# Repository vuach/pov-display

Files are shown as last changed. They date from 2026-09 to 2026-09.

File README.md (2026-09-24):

# ESP32 POV Display

Двухлопастной POV-дисплей на ESP32 с синхронизацией по датчику Холла.

## Текущая конфигурация

- две симметричные лопасти с активной длиной до 150 мм;
- по 20 APA102 на лопасть в первой сборке; до 21 после измерения;
- ESP32 DevKit V1 на роторе;
- шестиканальное токосъёмное кольцо;
- A2212 1000KV для первого прототипа, 1400KV не использовать;
- аккумулятор и ESC остаются на неподвижном основании;
- в односторонней Rev B модуль MP1584 расположен на роторе, через кольцо передаётся VBAT;
- целевой диапазон после механической валидации: 600–2400 RPM.

Проект пока находится на стадии стендовой проверки электроники. Вращение с установленным ротором запрещено до завершения расчёта, балансировки и изготовления закрытого защитного кожуха.

## Структура

- `docs/` — актуальная спецификация, архитектура, план сборки и безопасность;
- `hardware/` — BOM, расчёт питания, кольцо, разъёмы и двухлистовая принципиальная схема EasyEDA;
- `hardware/pcb/board-architecture.md` — окончательное функциональное разделение двух пользовательских плат и количество отверстий;
- `mechanical/` — требования к ротору, схема крепления мотора/ротора и предварительная параметрическая CAD-модель;
- `firmware/` — итоговая проектная прошивка, безопасная конфигурация по умолчанию и отдельно компилируемая полнофункциональная конфигурация;
- `tests/` — протоколы и результаты испытаний;
- `references/` — исходный практикум и фотографии компонентов.

## Ближайший этап

Автономные стендовые проверки полученных компонентов завершены без выявленных проблем. После получения кольца выполнить его прозвонку и нагрузочный тест. Сборка и вращение ротора остаются запрещены до завершения механического крепления, балансировки и защитного кожуха.

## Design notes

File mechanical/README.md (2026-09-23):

# Механическая часть

## Зафиксированная идея

- две геометрически одинаковые лопасти;
- активная длина каждой до 150 мм;
- светодиоды начинаются у ступицы и идут к периферии;
- ESP32, буфер, MP1584 и проводка располагаются максимально близко к оси;
- аккумулятор и ESC остаются на неподвижном основании;
- через кольцо в Rev B передаётся VBAT, а 5 В формируются модулем MP1584 на роторе.

Принцип крепления мотора, неподвижной X-крестовины, вращающегося адаптера и платы описан в [`motor-rotor-mounting.md`](motor-rotor-mounting.md).

## Предварительный материал

Для самих плат-лопастей предпочтителен FR4/G10. Он не должен быть единственным несущим элементом без расчёта и испытаний. Основную центробежную нагрузку должна принимать симметричная металлическая или карбоновая балка и металлическая зажимная ступица. FDM-печать допустима для держателей и кожухов, но не считается доказанно безопасной несущей ступицей.

## Данные, необходимые для CAD

| Параметр | Значение |
|---|---|
| Диаметр/геометрия вала A2212 | TBD |
| Межосевые размеры крепления мотора | TBD |
| Размеры кольца и полого вала | TBD |
| Корневая и активная длина лопасти | TBD / до 150 мм |
| Ширина и толщина FR4/G10 | TBD |
| Масса одной LED-ленты | TBD |
| Масса ESP32, буфера и проводов | TBD |
| Общая масса ротора | TBD |
| Материал несущей балки | TBD |
| Максимальные подтверждённые RPM | 0; вращение не проводилось |
| Принтер и рабочая область | TBD |

Финальную CAD-модель нельзя выпускать, пока эти значения не измерены. Для предварительной проверки компоновки подготовлена параметрическая модель [`cad/preliminary-assembly.scad`](cad/preliminary-assembly.scad). Все неподтверждённые размеры в ней явно отмечены как заглушки.

## Обязательные CAD-узлы

- ступица и соединение с мотором;
- симметричная несущая балка;
- крепления двух лопастей;
- крепление кольца;
- держатель ESP32 и буфера около оси;
- фиксация проводов и разгрузка пайки;
- основание мотора;
- полностью закрытый прозрачный кожух.

X-образная деталь из комплекта A2212 относится к неподвижному креплению корпуса мотора. Она не является ступицей ротора. Лопасти и плата крепятся к отдельной несущей детали, соединённой с вращающимся адаптером двигателя.

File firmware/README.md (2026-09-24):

# ESP32 POV — итоговая проектная прошивка

Версия: `1.0.0-project`.

Прошивка содержит полный предусмотренный программный контур устройства: две APA102-лопасти, синхронизацию Hall, BLE/Serial, хранение изображения и безопасный автомат управления ESC.

Слово «итоговая» относится к составу функций и компиляции. Прошивка не прошла испытания на собранном вращающемся устройстве и сама по себе не разрешает запуск ротора.

## Конфигурации сборки

| Environment | POV | Активный ESC | Назначение |
|---|---:|---:|---|
| `esp32dev` | заблокирован | заблокирован | безопасная сборка по умолчанию |
| `esp32dev-final` | включён | доступен после ARM | полнофункциональная проектная сборка, не прошивать до допуска |

```powershell
cd "C:\Users\vuach\Main Branch\Current\POV Display\firmware"
$env:PLATFORMIO_CORE_DIR="$PWD\.platformio-core"
& .\.venv\Scripts\platformio.exe run
& .\.venv\Scripts\platformio.exe run -e esp32dev-final
```

Команда `run` только компилирует. Она ничего не загружает в ESP32.

## Реализовано

- Hall на GPIO27 с отбрасыванием слишком близких импульсов и фильтрацией периода;
- 120 угловых столбцов, 20 LED на лопасть и сдвиг второй лопасти на 180°;
- два аппаратных SPI: GPIO18/19 и GPIO23/22;
- автоматическое гашение APA102 при потере синхронизации;
- изменение яркости и фазового нуля;
- запись отдельных пикселей, заливка кадра и тестовый рисунок;
- сохранение изображения, яркости и фазы во flash с контрольной суммой;
- двухступенчатое ARM-подтверждение ESC;
- плавное изменение PWM, heartbeat и аварии при потере Hall или превышении RPM;
- безопасные 1000 мкс после загрузки, STOP, потери BLE и любой ошибки ESC.

## Команды Serial и BLE

Serial: `115200`, окончание строки LF или CRLF. BLE-устройство называется `POV-Display`; UUID остались совместимыми с ранней версией.

| Команда | Назначение |
|---|---|
| `PING` | проверка связи |
| `VERSION` | версия прошивки |
| `STATUS` | состояние Hall и ESC |
| `HALL`, `ZERO`, `SIMRPM n` | диагностика датчика и расчёта RPM |
| `POVSTATUS`, `ESCSTATUS` | состояние подсистем |
| `ARM`, затем `ARM CONFIRM` за 3 с | двухступенчатое разрешение ESC |
| `THROTTLE n` | целевой PWM 1000…1600 мкс |
| `KEEPALIVE` | продление разрешения ESC; требуется чаще одного раза в секунду |
| `STOP`, `SAFE`, `OFF`, `DISARM` | 1000 мкс и гашение лопастей |
| `RESETFAULT` | перевод аварии обратно в DISARMED |
| `BRIGHT n` | глобальная яркость APA102, 0…31 |
| `PHASE n` | сдвиг фазового нуля в столбцах |
| `IMAGE CLEAR r g b` | заливка кадра цветом |
| `IMAGE PIXEL column radius r g b` | изменение одного пикселя |
| `IMAGE PATTERN` | восстановление диагностического рисунка |
| `IMAGE SAVE`, `IMAGE LOAD` | запись и чтение кадра из flash |
| `IMAGE STATUS` | параметры буфера изображения |

Передача полного кадра выполняется последовательностью `IMAGE PIXEL`, после чего используется `IMAGE SAVE`. Для удобной эксплуатации позже потребуется отдельное приложение-конвертер, но протокол хранения и изменения произвольного кадра уже реализован.

## Автомат ESC

Состояния: `LOCKED → DISARMED → ARM_PENDING → ARMED → RUNNING`. Любое нарушение переводит управление в `FAULT` и немедленно устанавливает 1000 мкс.

Аварийные условия:

- heartbeat отсутствует более 1 с;
- после начала разгона Hall не появился за 3 с;
- при работающем моторе Hall отсутствует более 0,5 с;
- RPM превышает 2600;
- BLE-соединение разорвано.

PWM изменяется ступенями по 5 мкс каждые 20 мс. Эти значения являются консервативной отправной точкой и должны уточняться по реальному ESC и механике.

## Результат сборки 2026-09-24

Обе конфигурации скомпилированы PlatformIO без ошибок.

| Конфигурация | RAM | Flash |
|---|---:|---:|
| безопасная `esp32dev` | 47 292 байт, 14,4% | 1 154 685 байт, 88,1% |
| функциональная `esp32dev-final` | 47 340 байт, 14,4% | 1 156 669 байт, 88,2% |

Загрузка в ESP32 и физическое испытание этой версии не выполнялись.

## Условия перед использованием функциональной сборки

1. Проверить CH5 кольца осциллографом.
2. Проверить лопасти неподвижно и подтвердить правильный порядок цветов.
3. Проверить аварийные переходы ESC без установленного ротора.
4. Выполнить балансировку и установить закрытый кожух.
5. Только после этого отдельно изменить процедуру допуска к прошивке `esp32dev-final`.

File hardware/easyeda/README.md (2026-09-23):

# EasyEDA

`pov-display-schematic-rev-a.json` — историческая двухлистовая схема стендовой Rev A, в которой MP1584 расположен до кольца. Для односторонней платы ротора Rev B актуальна архитектура с MP1584 на роторе из `docs/architecture-and-wiring.md` и `hardware/pcb/rotor-controller-rev-b-home-etch.md`; Rev A нельзя использовать как монтажную схему Rev B.

`pov-display-electrical-draft.json` — старый структурный черновик. Он сохранён только как обзор архитектуры и не должен использоваться вместо принципиальной схемы.

`exports/pov-display-schematic-rev-a.pdf` — читаемый экспорт Rev A. Исходный JSON обновлён до правила «20 LED по умолчанию, 21 после измерения» позднее PDF-экспорта; после проверки полученной ленты PDF требуется повторно экспортировать из EasyEDA. Электрическая распиновка от этого уточнения не меняется.

Схема предназначена для проверки архитектуры и соединений. Она не является производственной: библиотечные посадочные места, номиналы предохранителей, параметры кольца, полярность разъёмов и маркировку реальных модулей требуется проверить до изготовления.

Ограничение графических примитивов относится только к `pov-display-electrical-draft.json`. В Rev A электрические выводы и цепи присутствуют, однако ERC ещё не считается пройденным: условные символы требуется заменить проверенными библиотечными компонентами, назначить корпуса и сверить номера выводов с полученными деталями.

Основная схема генерируется командой:

```powershell
& "C:\Users\vuach\.cache\codex-runtimes\codex-primary-runtime\dependencies\node\bin\node.exe" "hardware/easyeda/generate-schematic.js"
```

Генератор структурного черновика: `generate-draft.js`.

После генерации файл импортируется через `Файл → Открыть → EasyEDA`.

Карта замены графических блоков компонентами библиотеки и собственными символами приведена в `library-replacement-map.md`.

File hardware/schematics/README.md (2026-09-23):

# Схемы соединений

- `wiring-netlist.csv` — актуальная таблица соединений для Rev B: через токосъёмное кольцо передаётся `VBAT`, а MP1584 установлен на роторе.
- `system-schematic.svg` и `system-schematic.png` — ранняя обзорная схема Rev A. Она оставлена для истории и не должна использоваться как монтажная схема Rev B.

Актуальные пояснения по монтажу находятся в `../assembly-and-wiring.md`, распиновка кольца — в `../slip-ring-pinout.md`, а односторонняя плата — в `../pcb/rotor-controller-rev-b-home-etch.md`.

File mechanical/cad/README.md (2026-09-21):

# Предварительная CAD-модель

Файл `preliminary-assembly.scad` содержит параметрическую компоновку двухлопастного POV-дисплея. Модель предназначена для проверки расположения узлов и оценки требуемого габарита кожуха.

Модель не является производственной. Экспорт деталей для печати, резки или установки на мотор запрещён до замены размеров-заглушек фактическими измерениями и проверки прочности.

## Отражено в модели

- две симметричные лопасти с активной длиной 150 мм;
- по 20 условных светодиодов на лопасть; 21 допускается после измерения;
- центральная несущая балка;
- условные объёмы ступицы, мотора, кольца и электроники;
- запас между концом лопасти и внешним габаритом кожуха;
- раздельное отображение ротора и защитного объёма.

## Размеры-заглушки

| Параметр | Значение в модели | Статус |
|---|---:|---|
| Диаметр вала | 3,2 мм | Только визуальная заглушка |
| Наружный диаметр ступицы | 36 мм | Только визуальная заглушка |
| Диаметр мотора | 28 мм | Только визуальная заглушка |
| Диаметр кольца | 22 мм | Только визуальная заглушка |
| Корневой отступ лопасти | 28 мм | Только компоновочное допущение |
| Ширина лопасти | 22 мм | Только компоновочное допущение |
| Толщина лопасти | 1,5 мм | Только компоновочное допущение |
| Габарит электроники | 58×32×13 мм | Условный объём |

## Использование

1. Установить OpenSCAD.
2. Открыть `preliminary-assembly.scad`.
3. Выбрать `view_mode`: `assembly`, `rotor` или `guard`.
4. После получения компонентов заменить только измеренные параметры.
5. Перед экспортом выполнить отдельный расчёт крепления и прочности.

OpenSCAD в текущем окружении не установлен, поэтому синтаксис подготовлен, но геометрический экспорт и проверка рендера ещё не выполнены.

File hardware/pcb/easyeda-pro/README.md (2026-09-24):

# EasyEDA Pro editable PCB

`rotor-controller-rev-a.kicad_pcb` is the editable interchange source for EasyEDA Pro. It contains the Rev A board outline, through-hole pads, named nets, routed top/bottom copper, mounting holes, top silkscreen envelopes and a bottom GND zone.

Import in EasyEDA Pro using `File -> Import -> KiCad`. EasyEDA Pro expects a ZIP archive, so select `rotor-controller-rev-a-kicad.zip`. The import was verified in EasyEDA Pro V3.2.149 on 2026-09-23: the PCB opened with editable pads, named nets, top/bottom tracks, outline, holes and silkscreen objects.

The standalone `.kicad_pcb` file is kept next to the ZIP as the editable interchange source.

This is a bench prototype. The board is `88 x 64 mm`; it is not mechanically approved for rotation.

## Rev B single-sided rotor carrier

`rotor-controller-rev-b-home-etch-kicad.zip` imports the editable single-sided home-etch revision. All routed copper and the GND zone are on `B.Cu`. Dashed `W1...W10`/`W4A` lines on `F.SilkS` are insulated component-side wire links, not copper tracks. Board size is `110 x 70 mm`.

This revision is an electrical prototype of the rotating-board circuit. It is not the final rotor layout: the revised component and hole requirements are listed in `../board-architecture.md`, while placement waits for the slip-ring and hub dimensions. It also requires a separate structural hub/beam and dynamic balancing before any powered rotation.

Regenerate from the same geometry as the Gerbers:

```powershell
& "C:\Users\vuach\.cache\codex-runtimes\codex-primary-runtime\dependencies\node\bin\node.exe" "hardware/pcb/generate-kicad-pcb.js"
```

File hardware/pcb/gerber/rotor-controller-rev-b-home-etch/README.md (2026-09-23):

# Rotor controller Rev B — home etch

Односторонняя нижняя медь для ручного травления. Компоненты устанавливаются сверху, пайка выполняется снизу. Красные пунктирные соединения на preview выполняются отдельными изолированными проводами сверху.

Печатать `rotor-controller-rev-b-home-etch-bottom-mirrored-1to1.svg` в масштабе 100 %. После печати проверить размер рамки `110 × 70 мм` и примерить ESP32 до травления.

Состав производственного архива:

- `*.GBL` — нижняя медь;
- `*.GKO` — контур платы;
- `*-NPTH.drl` — все отверстия без металлизации;
- `manufacturing.json` — параметры и координаты перемычек;
- `pad-map.csv` — карта площадок;
- `*-preview.svg` и `*-preview.bmp` — монтажный preview;
- `*-bottom-mirrored-1to1.svg` — шаблон тонерного переноса.

Электрическая проверка генератора не заменяет бумажную примерку компонентов, проверку механического крепления и балансировку ротора.

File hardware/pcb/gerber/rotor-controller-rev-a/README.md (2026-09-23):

# Gerber — rotor-controller Rev A

Назначение: первая двухслойная плата контроллера для стендовой электрической сборки ESP32 + SN74AHCT125 + двух ветвей APA102.

## Файлы производства

| Файл | Слой |
|---|---|
| `rotor-controller-rev-a.GTL` | верхняя медь |
| `rotor-controller-rev-a.GBL` | нижняя медь и земляной полигон |
| `rotor-controller-rev-a.GTS` | верхняя маска |
| `rotor-controller-rev-a.GBS` | нижняя маска |
| `rotor-controller-rev-a.GTO` | верхняя шелкография |
| `rotor-controller-rev-a.GKO` | контур платы |
| `rotor-controller-rev-a-PTH.drl` | металлизированные отверстия выводов и переходов |
| `rotor-controller-rev-a-NPTH.drl` | неметаллизированные монтажные отверстия 3,2 мм |
| `pad-map.csv` | координаты, номера выводов и цепи |
| `manufacturing.json` | параметры заказа |
| `rotor-controller-rev-a-preview.svg` | контрольный вид обоих слоёв |
| `rotor-controller-rev-a-preview.bmp` | растровый контрольный вид |

## Параметры

- FR-4, 2 слоя, 1,6 мм;
- медь 1 oz минимум;
- размер 88 × 64 мм;
- минимальная сигнальная дорожка 0,35 мм;
- питание 5 В разведено дорожками 1,2 мм;
- земля — полигон нижнего слоя;
- ESP32 — проверенный footprint Rev B, шаг вдоль ряда 2,52 мм;
- U4 — SN74AHCT125N PDIP-14, не 74HC125;
- J_A/J_B — 1×4, шаг 2,54 мм: `5V`, `GND`, `DI`, `CI`;
- J_RING — 1×6, шаг 2,54 мм: `5V`, `5V`, `GND`, `GND`, `ESC_PWM`, `NC`;
- J_HALL — 1×3: `GND`, `3V3`, `S`.

До нагрузочной проверки суммарный ток двух разъёмов лопастей ограничивается 0,9 А. Геометрия дорожек Rev A не является разрешением использовать максимальный паспортный ток всех APA102.

## Ограничение Rev A

Это электрически трассированный прототип, а не допущенный к вращению ротор. Размеры ступицы, её крепёж, масса сборки и динамическая балансировка ещё не подтверждены. Плату запрещено вращать до переноса проверенной электрической части в механически рассчитанную Rev B Rotor и испытаний в защитном кожухе.

Перед заказом комплект нужно дополнительно открыть в Gerber Viewer производителя и проверить, что контур распознан как `88 × 64 мм`, а сверловка содержит отверстия 1,0/1,1 и 3,2 мм.

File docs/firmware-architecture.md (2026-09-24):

# Архитектура прошивки

## Режимы безопасности

| Флаг сборки | Значение по умолчанию | Что разрешает |
|---|---:|---|
| `POV_DISPLAY_ENABLED` | `0` | Вывод на две APA102 только после изменения на `1` |
| `ENABLE_ESC_ACTIVE_TEST` | `0` | PWM выше безопасных 1000 мкс только после изменения на `1` |

Флаги независимы. Для неподвижного теста светодиодов можно разрешить только POV, оставив ESC заблокированным. Однако текущий рендер начинает вывод только после двух корректных импульсов Hall, необходимых для измерения периода.

## Поток данных

1. Прерывание GPIO27 фиксирует время Hall и отбрасывает импульсы ближе 5 мс.
2. Основной цикл атомарно получает время начала и период оборота.
3. Период принимается только в диапазоне 600–2400 RPM.
4. Время после импульса преобразуется в номер одного из 120 угловых столбцов.
5. Для лопасти A берётся текущий столбец, для лопасти B — столбец `+60`, то есть физический сдвиг 180°.
6. Два APA102-кадра передаются аппаратными SPI на 12 МГц.
7. Если новый Hall не появился до конца ожидаемого оборота, вывод гасится.

## Буфер изображения

Буфер имеет размер `120 × LEDS_PER_BLADE` пикселей RGB. При 20 LED он занимает 7200 байт. Сейчас при запуске формируется диагностическая сетка: угловые спицы, внутреннее кольцо и три цветных сектора. Полный белый намеренно не используется.

## Почему два SPI

Лопасти находятся с противоположных сторон ротора, но в один момент проходят разные координаты изображения. Раздельные DATA/CLOCK позволяют передавать каждой стороне свой столбец. Используются VSPI для GPIO18/19 и HSPI для GPIO23/22; выводы проходят через SN74AHCT125.

## Ограничения текущей версии

- порядок цветов и число 20 LED подтверждены только стендовыми испытаниями, но не в собранном роторе;
- фазовая задержка Hall относительно изображения не калибрована;
- полный кадр можно передать командами `IMAGE PIXEL`, однако быстрого двоичного протокола и приложения-конвертера пока нет;
- применяется простой IIR-фильтр периода, который потребуется настроить по реальному вращению;
- последовательная передача двух лопастей создаёт небольшую временную разницу;
- нет аппаратно подтверждённого контроля тока;
- сборка прошивки не подтверждает качество сигнала через буфер и проводку.

Проектный автомат ESC реализован отдельно в `esc_controller.cpp`: ARM требует подтверждения, управление требует heartbeat, PWM изменяется плавно, а потеря Hall и превышение RPM вызывают FAULT. Следующая безопасная проверка — испытать полнофункциональную сборку без установленного ротора и подтвердить сигналы приборами.

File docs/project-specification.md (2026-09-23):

# Спецификация двухлопастного POV-дисплея

## Назначение

Устройство формирует устойчивое изображение за счёт вращения двух радиальных лопастей с адресными APA102 и синхронизации по одному импульсу датчика Холла на оборот.

## Границы первой версии

- две одинаковые лопасти с активной длиной не более 150 мм;
- 20 APA102 на лопасть в первой сборке; допускается 21 после измерения фактического отрезка;
- 120 угловых столбцов на оборот как начальная программная конфигурация;
- расчётный рабочий диапазон 600–2400 RPM;
- ESP32, Hall и LED-интерфейс вращаются;
- аккумулятор, ESC и моторный силовой тракт неподвижны;
- в Rev B модуль MP1584 вращается вместе с платой, через кольцо передаётся VBAT;
- управление и загрузка изображения по BLE;
- эксплуатация только внутри закрытого ударопрочного кожуха.

## Электрические интерфейсы

| Функция | ESP32 | Примечание |
|---|---:|---|
| APA102 A DATA | GPIO18 | Через канал 1 SN74AHCT125 и 330–470 Ом |
| APA102 A CLOCK | GPIO19 | Через канал 2 SN74AHCT125 и 330–470 Ом |
| APA102 B DATA | GPIO23 | Через канал 3 SN74AHCT125 и 330–470 Ом |
| APA102 B CLOCK | GPIO22 | Через канал 4 SN74AHCT125 и 330–470 Ом |
| Hall | GPIO27 | KY-003 от 3,3 В; уровень OUT не выше 3,3 В |
| ESC PWM | GPIO25 | Через 220 Ом и канал 5 кольца |

## Функциональные требования

1. После сброса и потери связи ESC должен получать 1000 мкс.
2. При потере Hall светодиоды выключаются; управление мотором переходит в безопасное состояние.
3. Каждая лопасть получает собственный DATA/CLOCK, чтобы прошивка учитывала механический сдвиг 180°.
4. Яркость ограничивается по расчётному току, а не только визуальным процентом.
5. Прошивка измеряет период каждого оборота и пересчитывает момент вывода угловых столбцов.
6. USB разрешён только при механически заблокированном роторе и отключённом питании ESC.
7. Число LED задаётся одной константой прошивки и сверяется с фактически установленной лентой до первого включения.

## Критерии готовности к первому вращению

- известна масса всех вращающихся деталей и выполнена статическая балансировка;
- крепёж имеет механическую фиксацию и страховку от самоотвинчивания;
- кольцо прошло нагрузочный тест VBAT без перегрева и недопустимого падения напряжения;
- после MP1584 напряжение 5 В на роторе под нагрузкой не падает ниже 4,7 В;
- Hall выдаёт один чистый импульс за оборот;
- ESC PWM проверен осциллографом через кольцо;
- установлен закрытый защитный кожух;
- предусмотрено физическое отключение аккумулятора вне плоскости ротора.

## Ограничения

A2212 1000KV на 3S теоретически способен значительно превысить целевые обороты. Ограничение только в программе недостаточно: необходимы измерение RPM, физическое отключение питания, закрытый кожух и постепенная валидация скорости.

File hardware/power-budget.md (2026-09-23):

# Расчёт питания ротора

## Исходные данные

- две лопасти длиной до 150 мм;
- APA102 144 LED/м;
- первая сборка: 20 LED на лопасть;
- расчётный худший случай: 21 LED на лопасть, 42 суммарно;
- верхняя оценка одного LED: 60 мА при полном белом;
- ESP32: до 0,50 А кратковременно;
- Hall и буфер: ориентировочно до 0,03 А.

## Верхняя оценка

| Нагрузка | Ток 5 В | Мощность |
|---|---:|---:|
| 42 × APA102 | 2,52 А | 12,60 Вт |
| ESP32 | 0,50 А | 2,50 Вт |
| Hall + SN74AHCT125 | 0,03 А | 0,15 Вт |
| **Итого** | **3,05 А** | **15,25 Вт** |

MP1584 с номинальной маркировкой 3 А не имеет запаса для полного белого, а реальный допустимый непрерывный ток маленького модуля часто ограничен нагревом. Полный белый на 42 LED запрещён до нагрузочного теста.

## Начальные режимы

| Этап | LED | Программный предел LED-тока | Цель |
|---|---:|---:|---|
| 1 | 1 | 0,06 А | Проверка сигналов |
| 2 | 20 | 0,50 А | Проверка одной лопасти |
| 3 | 40 | 0,90 А суммарно | Две лопасти без вращения |
| 4 | 40–42 | По измерениям, не выше подтверждённого | Только после теплового теста |

С учётом ESP32 стартовый лимит 0,90 А для LED даёт приблизительно 1,43 А по 5 В. Проверять минимум 15 минут на эквивалентной нагрузке и фиксировать выходное напряжение и температуру.

## Критерии

- MP1584 без кольца: 5,00 В до подключения электроники;
- после добавления кольца измеряется падение VBAT на объединённых каналах питания и возврата;
- на роторе под нагрузкой: не ниже 4,70 В;
- отсутствие резких провалов при ручном вращении кольца;
- отсутствие роста температуры кольца, проводов и разъёмов;
- окончательный предел задаётся минимальным из возможностей DC-DC, кольца, проводки и разъёмов.

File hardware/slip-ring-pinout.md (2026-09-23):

# Шестиканальное токосъёмное кольцо

## Предварительная распиновка

| Канал | Статор | Ротор | Назначение |
|---:|---|---|---|
| 1 | `VBAT_STATOR_A` | `VBAT_ROTOR_A` | Необработанное питание Rev B |
| 2 | `VBAT_STATOR_B` | `VBAT_ROTOR_B` | Необработанное питание Rev B |
| 3 | `GND_STATOR_A` | `GND_ROTOR_A` | Земля |
| 4 | `GND_STATOR_B` | `GND_ROTOR_B` | Земля |
| 5 | `ESC_PWM_STATOR` | `ESC_PWM_ROTOR` | Управление ESC |
| 6 | `NC` | `NC` | Резерв, изолировать |

## До пайки

1. Пронумеровать оба конца кольца независимо от цвета проводов.
2. Прозвонить каждую пару и записать цвета в таблицу ниже.
3. Измерить сопротивление каждого канала в покое и при медленном вращении.
4. Найти паспортный допустимый ток одного канала.
5. Только после этого объединять 1+2 и 3+4.

Цвета жил кольца не наследуют проектную маркировку разъёмов. Фактические цвета записываются только по результатам прозвонки.

| Канал | Цвет статора | Цвет ротора | R покой | R при вращении | Проверено |
|---:|---|---|---:|---:|---|
| 1 | TBD | TBD | TBD | TBD | Нет |
| 2 | TBD | TBD | TBD | TBD | Нет |
| 3 | TBD | TBD | TBD | TBD | Нет |
| 4 | TBD | TBD | TBD | TBD | Нет |
| 5 | TBD | TBD | TBD | TBD | Нет |
| 6 | TBD | TBD | TBD | TBD | Нет |

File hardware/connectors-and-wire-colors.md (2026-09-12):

# Разъёмы и маркировка проводов

## Область применения

Имеющийся набор промаркирован как XH 2,54 мм. Совместимость с оригинальными JST-XH и конкретными ответными частями не считается подтверждённой: перед окончательной сборкой требуется пробная стыковка и проверка фиксации.

Разъёмы этого набора допускаются для датчика Холла, ESC PWM и сигнальных линий светодиодов. Цепи аккумулятор → ESC и три фазы мотора через них не проводить. Применение в цепи 5 В светодиодов допускается только после проверки допустимого тока, нагрева контактов и сечения провода.

Многоконтактный корпус нельзя надевать непосредственно на гребёнку ESP32, если требуемые выводы расположены не рядом. Для стенда допускаются отдельно изолированные гнездовые контакты. Для ротора требуется переходная плата либо закреплённый и защищённый от вибрации жгут.

## Назначение контактов

Нумерация ведётся со стороны проводов при защёлке корпуса сверху, слева направо. Перед пайкой нумерацию необходимо сверить прозвонкой с ответной частью.

| Разъём | Pin | Сеть | Цвет по проекту | Провод | Примечание |
|---|---:|---|---|---|---|
| `JH1` | 1 | `GND_ROTOR` | чёрный | 26 AWG | KY-003 `-` |
| `JH1` | 2 | `3V3_HALL` | красный | 26 AWG | KY-003 `+`; только 3,3 В |
| `JH1` | 3 | `HALL_OUT` | жёлтый | 26 AWG | KY-003 `S` → GPIO27 |
| `JLA` | 1 | `5V_ROTOR` | красный | 22 AWG | питание лопасти A |
| `JLA` | 2 | `GND_ROTOR` | чёрный | 22 AWG | земля лопасти A |
| `JLA` | 3 | `DATA_A` | синий | 26 AWG | выход буфера → APA102 DI |
| `JLA` | 4 | `CLOCK_A` | белый | 26 AWG | выход буфера → APA102 CI |
| `JLB` | 1 | `5V_ROTOR` | красный | 22 AWG | питание лопасти B |
| `JLB` | 2 | `GND_ROTOR` | чёрный | 22 AWG | земля лопасти B |
| `JLB` | 3 | `DATA_B` | зелёный | 26 AWG | выход буфера → APA102 DI |
| `JLB` | 4 | `CLOCK_B` | серый | 26 AWG | выход буфера → APA102 CI |
| `JESC` | 1 | `GND_ROTOR` | чёрный | 26 AWG | общая земля управления |
| `JESC` | 2 | `ESC_PWM_ROTOR` | оранжевый | 26 AWG | GPIO25 через 220 Ом |

Цвета в таблице задают проектную маркировку, а не подтверждают фактические цвета имеющихся проводов. Цвета жил токосъёмного кольца фиксируются отдельно после прозвонки.

## Контроль обжима

1. Зачистить только длину, входящую в передние лепестки контакта; ориентир 2–3 мм уточнить по фактическому контакту.
2. Передними лепестками обжать медную жилу, задними — изоляцию.
3. Вставить контакт до фиксации язычка и выполнить лёгкий тест натяжением.
4. Проверить отсутствие торчащих жил и замыкания на соседний контакт.
5. Прозвонить каждый готовый жгут до подключения питания.
6. На роторе добавить механическую разгрузку провода; усилие и вибрация не должны передаваться на контакт.

## Стоп-условия

- контакт выходит из корпуса при лёгком натяжении;
- корпус или контакт заметно нагревается под нагрузкой;
- сопротивление соединения нестабильно при шевелении провода;
- полярность либо нумерация не подтверждена прозвонкой;
- неизолированный контакт может коснуться соседнего вывода ESP32.

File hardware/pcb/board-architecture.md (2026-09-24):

# Состав печатных плат устройства

Статус: зафиксировано функциональное разделение. Для устройства требуются **две пользовательские печатные платы**: неподвижная интерфейсная плата и центральная плата ротора. Отдельные платы для лопастей в базовой версии не применяются: APA102 уже выполнены на заводской гибкой плате, а дополнительные переходники увеличили бы массу и дисбаланс.

Существующая `rotor-controller-rev-b-home-etch` является электрическим прототипом. Она не считается окончательной вращающейся платой, пока не известны размеры токосъёмного кольца, ступицы и несущей детали.

## PCB-S1 — неподвижная интерфейсная плата

### Назначение

Плата распределяет питание логики на четыре силовых канала кольца и передаёт PWM между вращающейся ESP32 и неподвижным ESC. Силовой ток двигателя через неё не проходит.

### Что устанавливается

- держатель отдельного предохранителя ветви ротора `F2`;
- входной электролит не менее `100 мкФ / 25 В`;
- разъём входа после главного выключателя;
- шестиконтактное подключение неподвижных проводов токосъёмного кольца;
- двухконтактное подключение `PWM + GND` к ESC;
- контрольные площадки `VBAT`, `GND`, `ESC_PWM`, `SPARE`;
- четыре крепёжных отверстия платы.

Главный предохранитель, выключатель, XT60, силовые провода ESC и три фазы двигателя остаются вне платы. Красный провод BEC от ESC изолируется и к плате не подключается.

### Отверстия и выводы

| Обозначение | Назначение | Отверстий |
|---|---|---:|
| `J_PWR_IN` | `VBAT`, `GND` после выключателя | 2 |
| `F2` | предохранитель ветви ротора | 2 |
| `J_RING_S` | CH1…CH6 кольца | 6 |
| `J_ESC` | `ESC_PWM`, `GND` | 2 |
| `C_IN` | электролит, `+` и `−` | 2 |
| `TP1…TP4` | четыре сквозные контрольные площадки | 4 |
| `H1…H4` | крепление M3, Ø3,2 мм | 4 |

Итого: `18` электрических отверстий и `4` крепёжных, всего `22` сверления. Если контрольные площадки сделать неперфорированными, останется `18` сверлений.

### Назначение шести каналов кольца

1. `VBAT_A`;
2. `VBAT_B`, параллельно первому после проверки кольца;
3. `GND_A`;
4. `GND_B`, параллельно третьему после проверки кольца;
5. `ESC_PWM`;
6. резерв, не соединён с динамиком до выбора его схемы управления.

### Требования

- односторонняя или двухслойная FR-4 толщиной 1,6 мм;
- дорожки двух ветвей `VBAT` и `GND` рассчитываются по измеренному току кольца, не менее 2,5 мм для прототипа с медью 35 мкм;
- зазор между `VBAT` и остальными сетями не менее 0,5 мм;
- входная полярность и вывод `1` кольца обозначаются на меди и шелкографии;
- разъёмы должны иметь фиксацию, исключающую переполюсовку;
- плата не заменяет главный предохранитель аккумулятора.

## PCB-R1 — центральная плата вращающейся части

На этом этапе фиксируются только состав и интерфейсы. Размер, форма, расположение компонентов, центральное отверстие и координаты крепления **не назначаются** до получения кольца и проектирования ступицы.

### Что должно находиться на плате

- ESP32 DevKit V1 30 pin в съёмных гнездовых колодках;
- MP1584, формирующий `5,00 В` после токосъёмного кольца;
- SN74AHCT125N в DIP-14 либо в качественной панельке DIP-14;
- резисторы `330–470 Ом` в четырёх линиях APA102;
- резистор `220 Ом` в линии ESC PWM;
- резистор подтяжки Hall `10 кОм` к `3,3 В`;
- керамический конденсатор `100 нФ` непосредственно у выводов 14 и 7 SN74AHCT125;
- электролит `100 мкФ / 25 В` на входе MP1584;
- электролит `220 мкФ / 10 В` на выходе MP1584;
- два электролита `1000 мкФ / 10 В`, по одному у выхода каждой лопасти;
- вход шести проводов вращающейся стороны кольца;
- разъём Hall на три контакта;
- два независимых четырёхконтактных выхода APA102;
- четыре крепления ESP32;
- минимум четыре крепления самой платы к отдельной несущей детали.

### Электрические отверстия

| Узел | Отверстий |
|---|---:|
| две колодки ESP32 по 15 | 30 |
| SN74AHCT125N DIP-14 | 14 |
| MP1584: `IN+`, `IN−`, `OUT+`, `OUT−` | 4 |
| `J_RING_R`: CH1…CH6 | 6 |
| `J_HALL`: GND, 3V3, SIGNAL | 3 |
| `J_BLADE_A`: 5V, GND, DATA, CLOCK | 4 |
| `J_BLADE_B`: 5V, GND, DATA, CLOCK | 4 |
| шесть резисторов по два вывода | 12 |
| пять конденсаторов по два вывода | 10 |

Итого: `87` электрических отверстий. Для ручного травления все они выполняются без металлизации.

### Механические отверстия

- `4 × Ø3,2 мм` под штатные отверстия ESP32;
- не менее `4 × Ø3,2 мм` для крепления платы к несущей детали;
- центральное отверстие пока отсутствует и добавляется только по измерениям кольца, ступицы, шайбы и гайки.

Предварительный итог без центрального отверстия: `87` электрических и `8` механических отверстий, всего `95` сверлений.

### Обязательные электрические требования

- GPIO18/19 обслуживают DATA/CLOCK лопасти A, GPIO23/22 — лопасти B;
- все четыре `/OE` SN74AHCT125 соединены с GND;
- APA102 получают 5-вольтовые DATA/CLOCK после AHCT125;
- питание лопастей разводится звездой; лопасть B не питается через лопасть A;
- GPIO27 получает сигнал Hall только уровня 3,3 В;
- GPIO25 идёт через 220 Ом к CH5 кольца;
- CH1+CH2 и CH3+CH4 объединяются только после прозвонки и нагрузочного теста кольца;
- USB должен оставаться доступным только при неподвижном и механически заблокированном роторе;
- каждый модуль и разъём получает механическую фиксацию, пайка не воспринимает центробежную нагрузку.

## Лопасти

Каждая из двух одинаковых лопастей содержит:

- несущую пластину из G10/FR-4 без медной разводки;
- отрезок из 20 APA102;
- четыре провода от центральной платы: `5V`, `GND`, `DATA`, `CLOCK`.

На самой лопасти не сверлятся сигнальные отверстия печатной платы: светодиодная лента подключается к своим четырём заводским входным площадкам. Количество и координаты механических отверстий лопасти определяются только расчётом несущей балки и одинаковы для обеих сторон.

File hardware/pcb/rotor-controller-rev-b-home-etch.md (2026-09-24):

# Плата ротора Rev B — одностороннее травление

Статус: электрическая разводка подготовлена, автоматическая проверка зазоров и связности пройдена. Это электрический прототип, а не окончательная плата вращающейся части. Уточнённый состав будущих плат приведён в [`board-architecture.md`](board-architecture.md); финальная компоновка ротора начнётся после измерения кольца и ступицы.

Серебристая X-крестовина из комплекта A2212 остаётся на неподвижном основании и крепит корпус мотора. Эта плата должна крепиться к отдельной несущей детали, соединённой с вращающимся адаптером двигателя. Подробнее: [`../../mechanical/motor-rotor-mounting.md`](../../mechanical/motor-rotor-mounting.md).

## Основные параметры

- размер платы: `110 × 70 мм`;
- медь: только нижняя сторона `B.Cu`;
- минимальная сигнальная дорожка: `0,8 мм`;
- минимальный расчётный зазор: `0,40 мм`;
- дорожка `VBAT`: `2,5 мм`;
- магистраль `5V`: `3,0 мм`;
- отверстия и площадки рассчитаны на ручное сверление, металлизация не требуется;
- footprint ESP32: проверенная версия Rev B, шаг контактов `2,52 мм`;
- MP1584 подключается четырьмя короткими проводами к крупным площадкам и механически фиксируется на плате.

## Верхние изолированные перемычки

Красные пунктирные линии на preview — это провода на стороне компонентов, а не второй слой меди.

| Перемычка | Сигнал | Откуда | Куда |
|---|---|---|---|
| W1 | DATA_A | R1 | J_A DI |
| W2 | CLOCK_A | R2 | J_A CI |
| W3 | DATA_B | R3 | J_B DI |
| W4 | CLOCK_B | R4 | J_B CI |
| W4A | CLOCK_B_BUF | U4 pin 11 | R4 |
| W5 | DATA_A_3V3 | ESP32 GPIO18 | U4 pin 2 |
| W6 | CLOCK_A_3V3 | ESP32 GPIO19 | U4 pin 5 |
| W7 | DATA_B_3V3 | ESP32 GPIO23 | U4 pin 9 |
| W8 | CLOCK_B_3V3 | ESP32 GPIO22 | U4 pin 12 |
| W9 | 3V3 | ESP32 3V3 | R6 и J_HALL VCC |
| W10 | HALL | ESP32 GPIO27 | R6 и J_HALL S |

Перемычки выполняются тонким многожильным изолированным проводом, укладываются вплотную к плате и фиксируются минимум в двух промежуточных точках. Свободно висящие провода на вращающейся части запрещены.

## Разъём кольца

| Контакт | Назначение |
|---|---|
| 1 | VBAT |
| 2 | VBAT, параллельно контакту 1 |
| 3 | GND |
| 4 | GND, параллельно контакту 3 |
| 5 | ESC PWM |
| 6 | резерв |

На этой ревизии MP1584 находится на роторе: через кольцо подаётся необработанное питание `VBAT`, а `5V` формируется после кольца. Это отличается от стендовой Rev A, где через кольцо предполагалось передавать уже готовые 5 В.

## Файлы

- `gerber/rotor-controller-rev-b-home-etch/rotor-controller-rev-b-home-etch-bottom-mirrored-1to1.svg` — зеркальный шаблон нижней меди; печатать строго 100 %, без «вписать в страницу»;
- `gerber/rotor-controller-rev-b-home-etch/rotor-controller-rev-b-home-etch.GBL` — нижняя медь;
- `gerber/rotor-controller-rev-b-home-etch/rotor-controller-rev-b-home-etch.GKO` — контур;
- `gerber/rotor-controller-rev-b-home-etch/rotor-controller-rev-b-home-etch-NPTH.drl` — сверловка;
- `easyeda-pro/rotor-controller-rev-b-home-etch-kicad.zip` — редактируемый импорт в EasyEDA Pro.

## Перед травлением

1. Распечатать шаблон на обычной бумаге в масштабе 100 %.
2. Проверить линейкой контрольный размер платы `110 × 70 мм`.
3. Проколоть оба ряда ESP32 и примерить реальную плату.
4. Приложить реальные SN74AHCT125, резисторы, конденсаторы и разъёмы.
5. Проверить фактическое размещение MP1584; его посадочные отверстия намеренно не зафиксированы из-за различий между клонами модуля.
6. Только после бумажной примерки переносить рисунок на фольгу.

## Ограничения вращения

- плата не должна нести лопасти как силовой элемент;
- требуется отдельная металлическая ступица/несущая балка;
- ESP32 и MP1584 фиксируются механически, пайка и гнёзда не считаются креплением;
- после сборки нужна статическая, затем динамическая балансировка;
- первое вращение допускается только в закрытом защитном кожухе, без USB-кабеля;
- до проверки реального тока 40 APA102 запрещён режим длительного полного белого свечения.

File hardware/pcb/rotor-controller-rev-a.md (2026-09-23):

# Плата контроллера ротора — Rev A

Статус: footprint ESP32 Rev B физически проверен. Выпущен Gerber Rev A для стендовой электрической платы. Вращение этой версии запрещено до проектирования интерфейса ступицы и динамической проверки.

## Состав платы

- съёмный ESP32 DevKit V1 30 pin;
- U4 `SN74AHCT125N` в DIP-14;
- C3 100 нФ непосредственно у выводов U4 14/7;
- четыре последовательных резистора 330–470 Ом на выходах DATA/CLOCK;
- разъёмы двух лопастей: `5V`, `GND`, `DI`, `CI`;
- разъём KY-003: `GND`, `3V3`, `S`;
- подтяжка Hall 10 кОм от `S` к `3V3`;
- вход питания ротора и вывод PWM к кольцу.

## Назначение каналов U4

| Канал | Вход ESP32 | Выход U4 | После резистора |
|---|---|---|---|
| 1 | GPIO18 | pin 3 | `DATA_A` → APA102 A `DI` |
| 2 | GPIO19 | pin 6 | `CLOCK_A` → APA102 A `CI` |
| 3 | GPIO23 | pin 8 | `DATA_B` → APA102 B `DI` |
| 4 | GPIO22 | pin 11 | `CLOCK_B` → APA102 B `CI` |

Все `/OE` постоянно соединяются с GND. U4 питается от 5 В. Прямая разводка DATA/CLOCK от ESP32 к APA102 запрещена: при 5-вольтовом питании входной порог APA102 не гарантирует распознавание 3,3 В.

## Правила размещения и трассировки

1. U4 и четыре резистора размещаются рядом с ESP32; резисторы — ближе к выходам U4.
2. C3 располагается максимально близко к выводам 14 и 7, с коротким возвратом в землю.
3. DATA и CLOCK каждой лопасти ведутся рядом с собственным GND, без длинных петель.
4. Питание двух лопастей разводится звездой; ток лопасти B не проходит через разъём или дорожку лопасти A.
5. Сигнальные дорожки не прокладываются параллельно силовым фазам мотора.
6. Для 5 В и GND применяются полигоны или широкие дорожки, ширина назначается после подтверждения фактического тока и толщины меди.
7. Разъёмы маркируются по функциям, а не по цвету неизвестных проводов.

## Что блокирует механическую Rotor Rev B

- размеры вращающейся ступицы и запретной зоны вокруг оси;
- размеры и ориентация разъёмов лопастей, кольца и Hall;
- выбранная толщина платы, меди и допустимый ток питания.

Электрическую Rev A можно изготовить и испытывать только неподвижно. Для вращающейся версии потребуется новый контур и механическое крепление, даже если электрическая часть останется без изменений.

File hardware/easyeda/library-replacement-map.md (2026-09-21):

# Замена графических блоков компонентами EasyEDA

Названия библиотечных элементов могут немного различаться между локальной и веб-версиями EasyEDA. Поиск следует выполнять по английским ключевым словам. До выбора посадочного места требуется сверить реальную деталь штангенциркулем и по маркировке.

## Лист 01 — Stationary Power

| Блок | Что установить | Поиск в библиотеке | Контакты и замечания |
|---|---|---|---|
| `J1 Li-Po 3S` | Двухконтактный разъём | `XT60`, при отсутствии — `CONN_01X02` | 1 — `VBAT+`, 2 — `GND_STATOR`. Пол разъёма выбрать по фактической батарее. |
| `F1 MAIN FUSE` | Предохранитель | `FUSE` | Номинал пока `TBD`. Для внешнего держателя посадочное место не назначать либо вывести два контакта. |
| `SW1 DC SWITCH` | Однополюсный выключатель | `SW_SPST` | Только DC-rated выключатель или anti-spark узел. |
| `ESC1 ESC 30 A` | Собственный символ ESC либо три разъёма | `CONN_01X02`, `CONN_01X03` | Питание: `BAT+`, `BAT-`; двигатель: `U`, `V`, `W`; управление: `PWM`, `GND`, `BEC_5V`. `BEC_5V` оставить `NC`, пока схема питания не подтверждена. |
| `M1 A2212 1000KV` | Трёхфазный двигатель | `MOTOR_BLDC`, `BRUSHLESS MOTOR`; при отсутствии — `CONN_01X03` | Контакты `U`, `V`, `W`. Направление меняется перестановкой любых двух фаз. |
| `F2 LOGIC FUSE` | Предохранитель | `FUSE` | Предварительно 3 A; окончательный номинал после нагрузочного теста. |
| `U1 MP1584 DC-DC` | Собственный символ модуля на 4 вывода | `MP1584 MODULE`; если найден только `MP1584EN`, его не использовать вместо готовой платы | `IN+`, `IN-`, `OUT+`, `OUT-`. Для схемы допустим собственный символ без PCB footprint. |
| `C1` | Полярный электролитический конденсатор 100 мкФ, не менее 25 В | `CP`, `CAP POLARIZED` | Между `VBAT+` и `GND_STATOR`, рядом со входом MP1584. |
| `C2` | Полярный электролитический конденсатор 220 мкФ, не менее 10 В | `CP`, `CAP POLARIZED` | Между `+5V_STATOR` и `GND_STATOR`, рядом с выходом MP1584. |
| `SR1` | Разъём 1×6 либо собственный символ кольца | `CONN_01X06` | 1–2: `+5V`; 3–4: `GND`; 5: `ESC_PWM`; 6: `BEEP_CTRL/NC`. Footprint не нужен, если кольцо подключается проводами. |
| `JROTOR` | Разъём жгута питания ротора, если он физически предусмотрен | `CONN_01X04` | 1–2: `+5V_ROTOR`; 3–4: `GND_ROTOR`. Если отдельного разъёма не будет, блок удалить и соединить кольцо непосредственно с шинами. |
| `J5 ESC PWM RETURN` | Не отдельный компонент, а имя цепи | `NETLABEL` | Использовать метку `ESC_PWM`; отдельный разъём нужен только при разъёмном жгуте. |
| `R6` | Резистор 1 кОм | `R`, `RESISTOR` | Между `BEEP_CTRL` и базой Q1. |
| `Q1` | NPN-транзистор | `2N3904` или фактически купленный `S8050` | Эмиттер — GND, коллектор — минус динамика, база — через R6. Footprint выбирать строго по корпусу и распиновке конкретного транзистора. |
| `BZ1` | Активный зуммер 5 В | `BUZZER`, `ACTIVE BUZZER` | Плюс — `+5V_STATOR`, минус — коллектор Q1. Для электромагнитного зуммера добавить обратный диод; для пьезоактивного обычно не требуется. |

## Лист 02 — Rotor Logic

| Блок | Что установить | Поиск в библиотеке | Контакты и замечания |
|---|---|---|---|
| `U3 ESP32 DevKit V1` | Готовый символ `ESP32 DEVKIT V1 30 PIN` либо собственный 30-контактный модуль | `ESP32 DEVKIT V1`, `DOIT ESP32 DEVKIT V1 30PIN` | Сторонние модели нельзя принимать без проверки. Для текущей схемы нужны `VIN`, `3V3`, `GND`, GPIO18, 19, 22, 23, 25, 26, 27. |
| `U4` | Четырёхканальный буфер `74AHCT125` | `74AHCT125`, `SN74AHCT125N` | Для DIP-корпуса выбрать `DIP-14`. Не заменять на `74HC125`: порог входного уровня отличается. |
| `C3` | Керамический конденсатор 100 нФ | `C`, `CAPACITOR` | Между выводами U4 14 и 7, максимально близко к корпусу. |
| `R1–R4` | Четыре резистора 330–470 Ом | `R`, `RESISTOR` | Ставятся последовательно на выходах U4 возле буфера. |
| `JLA`, `JLB` | Два входных разъёма лопастей 1×4 | `CONN_01X04`; для платы — `JST XH 4P`, например `B4B-XH-A` | Контакты назначить как `+5V`, `GND`, `DATA/DI`, `CLOCK/CI`. Фактический порядок конкретной ленты проверить по надписям и стрелке. |
| `C4`, `C5` | Полярные электролиты 1000 мкФ, не менее 10 В | `CP`, `CAP POLARIZED` | По одному у входа каждой лопасти, между `+5V_ROTOR` и `GND_ROTOR`. |
| `JH1/H1 KY-003` | Собственный символ модуля на 3 вывода либо разъём 1×3 | `CONN_01X03`; для самого датчика можно искать `A3144`, `AH3144` | Для модуля: `-` — GND, `+` — 3V3, `S` — GPIO27. Расположение выводов сверить по надписям на имеющемся модуле. |
| `R5` | Резистор 220 Ом | `R`, `RESISTOR` | GPIO25 → R5 → `ESC_PWM` → канал 5 кольца. |
| `SR1-5`, `SR1-6` | Не отдельные компоненты | `NETLABEL`, `PORT` | Это контакты 5 и 6 единого компонента SR1 на первом листе. Межлистовые связи оформить портами `ESC_PWM` и `BEEP_CTRL`. |

## Распиновка U4 SN74AHCT125N

| Вывод | Назначение в проекте |
|---:|---|
| 1 | `1OE` → GND |
| 2 | `1A` ← GPIO18 |
| 3 | `1Y` → R1 → `DATA_A` |
| 4 | `2OE` → GND |
| 5 | `2A` ← GPIO19 |
| 6 | `2Y` → R2 → `CLOCK_A` |
| 7 | GND |
| 8 | `3Y` → R3 → `DATA_B` |
| 9 | `3A` ← GPIO23 |
| 10 | `3OE` → GND |
| 11 | `4Y` → R4 → `CLOCK_B` |
| 12 | `4A` ← GPIO22 |
| 13 | `4OE` → GND |
| 14 | `VCC` → +5V |

## Символ ESP32, если потребуется создать вручную

Для 30-контактной платы при USB-разъёме снизу подписи на имеющемся экземпляре расположены так:

- левый ряд сверху вниз: `EN`, `VP`, `VN`, `D34`, `D35`, `D32`, `D33`, `D25`, `D26`, `D27`, `D14`, `D12`, `D13`, `GND`, `VIN`;
- правый ряд сверху вниз: `D23`, `D22`, `TX0`, `RX0`, `D21`, `D19`, `D18`, `D5`, `TX2`, `RX2`, `D4`, `D2`, `D15`, `GND`, `3V3`.

Габариты платы, расстояние между рядами и нумерацию выводов для посадочного места требуется снять с реального экземпляра. У 30-контактных клонов DevKit V1 встречаются разные размеры.

## Рекомендуемый порядок перестройки

1. Установить стандартные R, C, FUSE, SW_SPST, Q1 и U4.
2. Все внешние модули временно представить разъёмами.
3. Создать собственные символы `ESP32_DEVKIT_V1_30P`, `MP1584_MODULE`, `ESC_30A` и `SLIP_RING_6CH`.
4. Заменить длинные линии именами цепей и межлистовыми портами.
5. Запустить ERC и отдельно проверить питание, незадействованные выводы и направление входов/выходов.
6. Посадочные места назначать только после измерения реальных деталей.

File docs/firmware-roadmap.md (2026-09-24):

# Состояние разработки прошивки

## Реализовано к 2026-09-24

- R1: Hall, счётчик импульсов, фильтр периода, RPM и статистика отброшенных импульсов;
- R2: две независимые APA102 по двум аппаратным SPI;
- R3: буфер `120 × 20`, сдвиг второй лопасти 180°, фазовая поправка и blackout;
- R4: двухступенчатый ARM, плавный PWM, heartbeat, предел RPM, контроль потери Hall и аварийный останов;
- R5: произвольное изменение кадра командами, контрольная сумма и сохранение во flash;
- BLE и Serial используют один обработчик команд;
- безопасная и полнофункциональная конфигурации успешно компилируются.

## Не относится к написанию кода

Проектная реализация не становится эксплуатационной до завершения следующих физических работ:

1. Проверка PWM через токосъёмное кольцо.
2. Калибровка фазового нуля на собранном роторе.
3. Измерение минимального устойчивого PWM конкретного ESC и мотора.
4. Подтверждение реального ограничения RPM.
5. Испытание всех аварийных остановов без лопастей.
6. Статическая и динамическая балансировка.
7. Испытание в закрытом кожухе.

## Возможные улучшения после стендовых испытаний

- двоичный BLE-протокол для быстрой загрузки полного кадра;
- приложение-конвертер PNG/текста в 120 угловых столбцов;
- двойная буферизация изображения;
- адаптивная фильтрация RPM по реальному сигналу Hall;
- журнал причин остановки с сохранением во flash.

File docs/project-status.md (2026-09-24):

# Текущее состояние проекта

Дата актуализации: 2026-09-24.

## Подтверждено

- ESP32 DevKit V1 определяется как CP210x на COM5.
- Между `3V3` и `GND` измерено 3,30 В постоянного напряжения.
- Тестовая прошивка собрана и загружена.
- Serial 115200 и единый обработчик BLE/Serial подготовлены; итоговое BLE-имя — `POV-Display`. Стендовые команды ранней версии проверены, новые команды ARM/IMAGE пока подтверждены только компиляцией.
- Активный ESC PWM программно заблокирован на безопасных 1000 мкс.
- Шестиканальное токосъёмное кольцо заказано, но ещё не получено.
- Есть набор XH-совместимых разъёмов 2,54 мм на 2–5 контактов.
- Принята двухлопастная компоновка: две одинаковые лопасти длиной до 150 мм.
- Подготовлена предварительная параметрическая OpenSCAD-модель компоновки; размеры-заглушки не считаются подтверждёнными.
- Подготовлена двухлистовая принципиальная схема EasyEDA Rev A: неподвижная силовая часть и логика ротора. Компоненты имеют электрические выводы, соединения и имена цепей; окончательная проверка ERC, посадочных мест и BOM ожидает уточнения фактических моделей деталей.
- Реализован и собран без ошибок заблокированный POV-модуль: 120 столбцов, две независимые APA102, сдвиг 180° и гашение при потере Hall. Аппаратная проверка не выполнена.
- KY-003 проверен от 3,3 В: OUT 3,29/0,01 В с внешней подтяжкой 10 кОм; один поднос магнита зарегистрирован как один импульс GPIO27.
- Полученная APA102 имеет 20 LED на 140 мм. Силовые провода и направление входа подтверждены; порядок синего и зелёного CI/DI ожидает проверки под питанием.
- Li-Po 3S 1500 мА·ч 45C имеет напряжение 11,8 В на силовом разъёме.
- Посадочный шаблон ESP32 Rev B физически проверен. Выпущен Gerber электрической платы Rev A размером 88 × 64 мм; версия предназначена только для неподвижной проверки и не заменяет механически рассчитанную плату ротора.
- Подготовлена односторонняя плата ротора Rev B для ручного травления: `110 × 70 мм`, только нижняя медь, 11 фиксируемых изолированных перемычек сверху. Проверены геометрические зазоры и связность цепей; бумажная примерка, интерфейс ступицы и балансировка ещё не выполнены.
- Зафиксировано окончательное функциональное разделение на две пользовательские платы: неподвижную интерфейсную и центральную плату ротора. Состав и число отверстий описаны в `hardware/pcb/board-architecture.md`; расположение элементов финальной платы ротора намеренно не назначено до получения кольца.
- Итоговая проектная прошивка реализует Hall, POV, хранение изображения и безопасный автомат ESC. Безопасная и полнофункциональная конфигурации компилируются; загрузка и физическая проверка новой версии не выполнялись.
- По сообщению сборщика, все полученные компоненты прошли предусмотренные автономные стендовые проверки без выявленных проблем. Токосъёмное кольцо ещё отсутствует; зависящие от него и механические испытания не закрыты.

## Рабочие решения

| Вопрос | Решение | Статус |
|---|---|---|
| Мотор | A2212 1000KV | Предварительно; точные размеры и режим не подтверждены |
| Мотор 1400KV | Не использовать в первом прототипе | Принято |
| Светодиоды | APA102, две независимые ветви по 20 LED | Количество и длина подтверждены; электрический тест ожидается |
| Сигналы LED | A: GPIO18/19, B: GPIO23/22 | Предварительно |
| Hall | KY-003, GPIO27, питание 3,3 В, подтяжка 10 кОм | Стендовая проверка PASS |
| ESC PWM | GPIO25 через канал 5 кольца | Активное управление пока заблокировано |
| Питание ротора | MP1584 на роторе; через кольцо передаётся VBAT | Принято для Rev B; требует нагрузочного теста и проверки помех |
| Каналы кольца | 1+2: VBAT; 3+4: GND; 5: PWM; 6: резерв | До прозвонки и проверки тока не окончательно |
| Разъёмы | `JH1`, `JLA`, `JLB`, `JESC`; единая цветовая маркировка | Распиновка подготовлена, физические жгуты не проверены |

## Подготовлены проверки

- протокол KY-003 с измерением питания, уровней OUT и счётчика прошивки;
- протокол MP1584 с настройкой 5,00 В и четырьмя ступенями нагрузки;
- единый файл результатов без предварительного присвоения `PASS`.

## Не подтверждено

- точная модель, сопротивление и допустимый ток каждого канала кольца;
- устойчивость MP1584 под нагрузкой ротора;
- форма фронтов KY-003 на рабочей скорости без осциллографа;
- размеры вала и крепёжная геометрия мотора;
- масса, жёсткость, баланс и критические обороты ротора;
- минимальные устойчивые обороты связки A2212 и ESC;
- способность защитного кожуха удержать фрагменты.

## Запрет до следующей ревизии

Не подключать мотор к установленному ротору и не снимать блокировку ESC до закрытия всех пунктов механической безопасности и проведения тестов внутри кожуха.

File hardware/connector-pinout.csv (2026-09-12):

connector | pin | net | color | wire | notes
JH1 | 1 | GND_ROTOR | black | 26 AWG | KY-003 minus
JH1 | 2 | 3V3_HALL | red | 26 AWG | KY-003 plus; 3.3 V only
JH1 | 3 | HALL_OUT | yellow | 26 AWG | KY-003 S to GPIO27
JLA | 1 | 5V_ROTOR | red | 22 AWG | blade A power
JLA | 2 | GND_ROTOR | black | 22 AWG | blade A ground
JLA | 3 | DATA_A | blue | 26 AWG | buffer to APA102 DI
JLA | 4 | CLOCK_A | white | 26 AWG | buffer to APA102 CI
JLB | 1 | 5V_ROTOR | red | 22 AWG | blade B power
JLB | 2 | GND_ROTOR | black | 22 AWG | blade B ground
JLB | 3 | DATA_B | green | 26 AWG | buffer to APA102 DI
JLB | 4 | CLOCK_B | gray | 26 AWG | buffer to APA102 CI
JESC | 1 | GND_ROTOR | black | 26 AWG | control ground
JESC | 2 | ESC_PWM_ROTOR | orange | 26 AWG | GPIO25 through 220 ohm

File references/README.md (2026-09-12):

# Справочные материалы

- `source-documents/` — исходный практикум без правок;
- `component-screenshots/` — фотографии и скриншоты карточек компонентов.

Справочные материалы не являются окончательной спецификацией. Маркировки и размеры физических компонентов имеют приоритет перед изображениями продавцов.

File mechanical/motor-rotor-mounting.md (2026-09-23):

# Крепление мотора, ротора и электронной платы

Статус: принцип сборки зафиксирован, точная геометрия ожидает измерения адаптера и токосъёмного кольца.

## Неподвижная часть

Серебристая X-образная крестовина из комплекта A2212 является **креплением корпуса мотора**. Она прикручивается к основанию устройства и при работе не вращается.

К крестовине нельзя крепить:

- лопасти;
- плату ротора;
- магнит синхронизации;
- вращающуюся часть токосъёмного кольца.

## Вращающаяся часть

К валу или колоколу мотора устанавливается комплектный вращающийся адаптер. На фотографии это серебристая конусная деталь, поставленная отдельно от крестовины. Точный способ её установки необходимо подтвердить осмотром и измерениями конкретного комплекта.

Предполагаемая последовательность узлов:

```text
неподвижное основание
    └── X-крестовина
        └── корпус мотора
            └── вращающийся адаптер
                └── металлическая ступица или несущая балка
                    ├── лопасть A
                    ├── электронная плата
                    └── лопасть B
```

## Роль стеклотекстолита

Фольгированный стеклотекстолит используется как электрическая плата. Он не принимается за доказанно безопасную несущую деталь ротора.

- лопасти крепятся к металлической или рассчитанной карбоновой балке;
- плата крепится к этой балке минимум в трёх точках, предпочтительно четырьмя винтами через стойки;
- одно центральное отверстие не считается достаточным креплением;
- ESP32, MP1584, разъёмы и провода получают отдельную механическую фиксацию;
- пайка и штыревые разъёмы не должны воспринимать центробежную нагрузку.

## Центральное отверстие платы

Центральное отверстие требуется только в том случае, если через плату проходит вал, крепёж адаптера или токосъёмное кольцо. Его нельзя назначать до получения размеров всех трёх узлов.

Вокруг готового отверстия оставляется зона без меди и компонентов. Размер зоны определяется диаметром вращающейся детали, шайбы, гайки и необходимым монтажным зазором; произвольное отверстие «по центру» сейчас не добавляется.

## Что измерить до финальной платы

1. Диаметр и длину посадочной части вращающегося адаптера.
2. Диаметр резьбы, шайбы и гайки адаптера.
3. Расположение крепёжных отверстий несущей ступицы.
4. Наружный диаметр, длину и центральное отверстие токосъёмного кольца.
5. Расстояние от плоскости мотора до плоскости ротора.
6. Доступный симметричный габарит центральной электроники.
7. Массу платы, MP1584, ESP32, проводов и разъёмов.

До этих измерений Rev B считается электрическим макетом компоновки. Травление допустимо только после бумажной примерки, а вращение — после проектирования отдельной несущей детали, фиксации компонентов и балансировки.

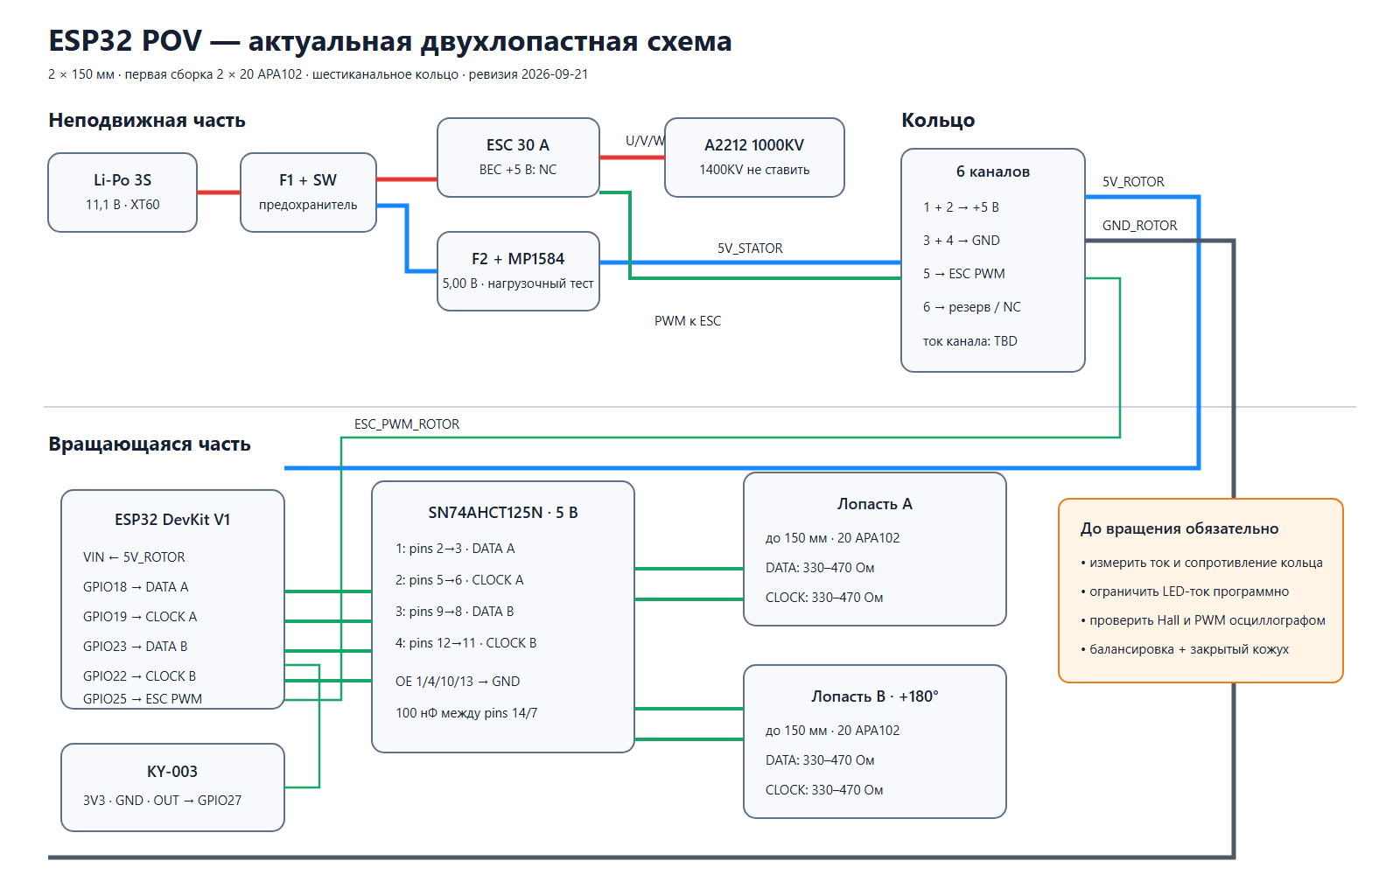
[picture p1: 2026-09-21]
hardware/schematics/system-schematic.png

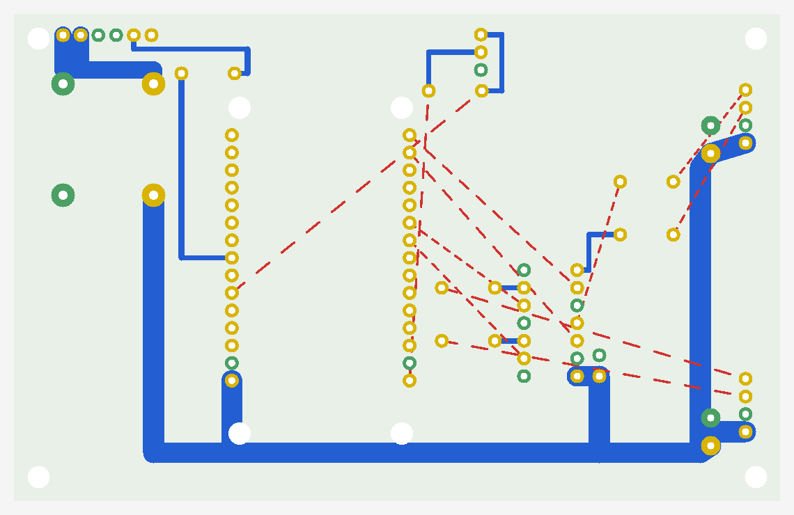
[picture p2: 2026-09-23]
hardware/pcb/gerber/rotor-controller-rev-b-home-etch/rotor-controller-rev-b-home-etch-preview.bmp

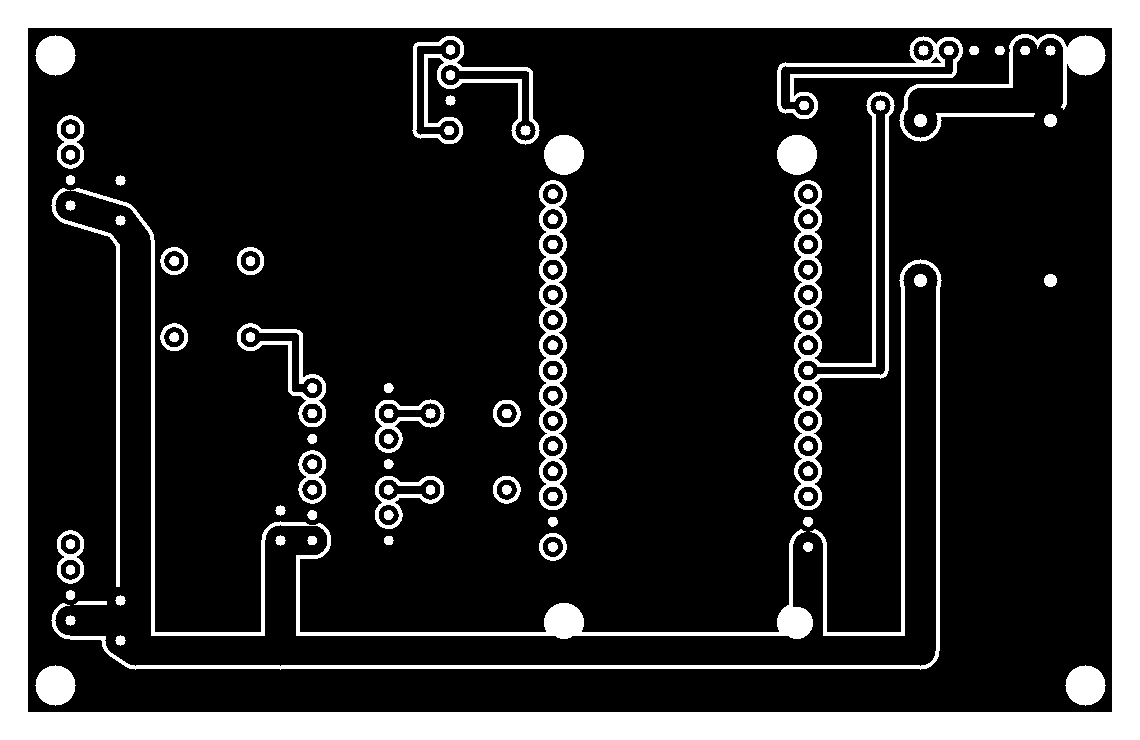
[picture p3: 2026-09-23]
hardware/pcb/gerber/rotor-controller-rev-b-home-etch/rotor-controller-rev-b-home-etch-bottom-mirrored-preview.bmp

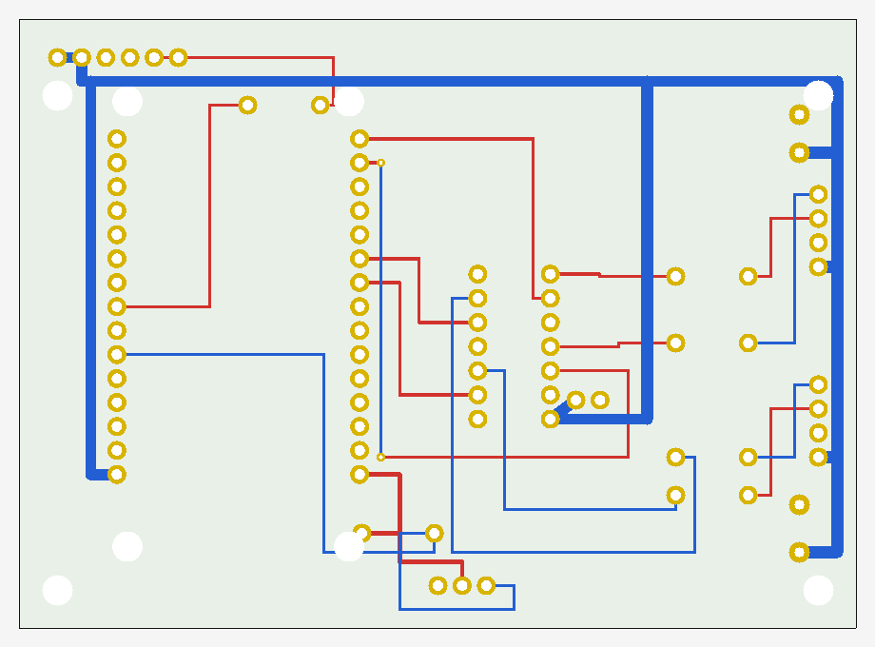
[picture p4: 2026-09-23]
hardware/pcb/gerber/rotor-controller-rev-a/rotor-controller-rev-a-preview.bmp

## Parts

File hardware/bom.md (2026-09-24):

# Ведомость компонентов

Статус актуален на 2026-09-24. `Проверен` означает, что предусмотренная автономная стендовая проверка пройдена без выявленных проблем; числовые журналы части испытаний в репозиторий не переданы.

| Узел | Кол-во | Статус | Критичная проверка |
|---|---:|---|---|
| ESP32 DevKit V1, CP2102, USB-C | 1 | Есть, проверена | Питание 3,30 В; COM5; прошивка работает |
| MP1584 DC-DC | 1 | Проверен, MP1584EN | Повторить проверку после установки на ротор и питания через кольцо |
| KY-003 | 1 | Есть, проверен | OUT 3,29/0,01 В; требуется внешняя подтяжка 10 кОм |
| A2212/13T 1000KV | 1 | Проверен автономно без ротора | Крепление, ток и минимальные устойчивые RPM проверять повторно в собранном узле |
| A2212 1400KV | 1 | Запас | Не устанавливать в первый ротор |
| Шестиканальное кольцо | 1 | Заказано, не получено | Ток канала, сопротивление, цвета и габариты |
| APA102 144 LED/м IP30 | 2 отрезка по 20 LED | Проверены автономно и совместно | Повторить проверку после окончательного монтажа |
| SN74AHCT125N PDIP-14 | 1 | Проверен, четыре канала работают | Обязательный преобразователь 3,3→5 В; 74HC125 не заменяет AHCT125 |
| Резистор 330–470 Ом | 4 | Резисторы есть | По одному на DATA/CLOCK каждой лопасти |
| Резистор 220 Ом | 1 | Резисторы есть | Последовательно в ESC PWM |
| Резистор 10 кОм | 1 | Есть, установлен на стенде | Обязательная внешняя подтяжка Hall `S` к 3,3 В |
| Конденсатор 100 нФ керамический | минимум 3 | Требуется/уточнить | Один обязательно непосредственно между выводами 14 и 7 AHCT125; остальные у точек питания логики |
| Электролит 1000 мкФ ≥10 В | 1–2 | Есть/уточнить | Полярность; у питания LED |
| Электролит 220 мкФ ≥10 В | 1 | Есть/уточнить | Выход DC-DC |
| Электролит 100 мкФ ≥25 В | 1 | Есть/уточнить | Вход DC-DC |
| ESC 30 A, 2–4S, BEC 5 В/2 А | 1 | Проверен автономно без кольца | Повторить PWM через CH5 кольца; BEC изолировать |
| Li-Po 3S 1500 мА·ч 45C | 1 | Есть, 11,8 В | Проверить напряжения отдельных банок; разъём XT60 |
| Балансирное ЗУ IMAX B6 | 1 | Статус уточнить | Подлинность и питание зарядника |
| Главный предохранитель и держатель | 1 | Требуется | Номинал выбрать после измерения моторного тока |
| Предохранитель логики | 1 | Требуется | Предварительно 3 А; уточнить по DC-DC и проводке |
| DC-rated выключатель/anti-spark | 1 | Требуется | 3S и измеренный ток ESC |
| Провода 14–16 AWG | По месту | Требуется | Аккумулятор → ESC |
| Провода 22 AWG | По месту | Есть/уточнить | Короткие линии 5 В на роторе |
| Провода 26 AWG | По месту | Есть | Сигналы |
| Набор XH-совместимых разъёмов 2,54 мм, 2–5 pin | 1 | Есть | Для сигналов и маломощных цепей; совместимость и допустимый ток проверить |
| Кримпер для XH-контактов | 1 | Статус уточнить | Отдельный обжим жилы и изоляции |
| Металлическая ступица | 1 | Требуется | Совместимость с A2212 и кольцом |
| Несущая балка металл/карбон | 1 | Требуется | Симметрия и расчёт прочности |
| Лопасти FR4/G10 | 2 | Материал не утверждён | Одинаковые масса и геометрия |
| Закрытый прозрачный кожух | 1 | Обязателен | Полное перекрытие плоскости ротора |

## Нельзя считать BOM завершённым

До получения кольца и измерения деталей нельзя окончательно выбрать крепление, предохранители, проводку и режим питания. Ссылки на продавцов, цены, массу и измеренные характеристики добавляются после полной приёмки.

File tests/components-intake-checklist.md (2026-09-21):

# Приёмка компонентов

Компоненты сначала осматриваются и измеряются без подачи питания. Фото маркировки сохраняются до монтажа.

## Общая фиксация

Для каждой детали записываются точное название, количество, масса, размеры, состояние разъёмов и пайки, ссылка на паспорт или карточку товара, фотографии с обеих сторон и расхождения с BOM.

## Электрические компоненты

| Деталь | Проверить до питания | Первый тест |
|---|---|---|
| APA102 | Стрелки направления, `5V/GND/DI/CI`, число LED | Одна ветвь, минимальная яркость, ограничение тока |
| SN74AHCT125 | Маркировка, ключ корпуса, выводы | 5 В, 100 нФ, `/OE` на GND |
| ESC | Ток, диапазон Li-Po, BEC, порядок проводов | Сначала только сигнал осциллографом |
| Li-Po | Число банок, напряжение банок, повреждения | Подходящим зарядником в безопасном месте |
| Кольцо | Количество и цвета жил, сопротивление, изоляция | Прозвонка при ручном вращении |
| Электролиты | Ёмкость, напряжение, полярность | Проверка на отсутствие замыкания |
| Зуммер/динамик | Активный или пассивный, напряжение, ток | Через драйвер, не напрямую от GPIO |

## Механика

Заполнить `mechanical/measurement-sheet.md`. Отдельно проверить совместимость вала, ступицы, отверстия кольца и крепежа. Размер из карточки товара не заменяет измерение штангенциркулем.

## Запреты

- не подключать Li-Po к неизвестной схеме;
- не соединять BEC ESC и MP1584 параллельно;
- не подавать 5 В на `3V3` или GPIO ESP32;
- не включать мотор с установленными лопастями;
- не назначать каналы кольца только по цвету провода.

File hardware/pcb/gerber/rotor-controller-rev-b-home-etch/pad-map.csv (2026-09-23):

ref | pin | x_mm | y_mm | net | drill_mm | pad_mm
U1 | L1-VIN | 31.2375 | 17.3600 | 5V | 1.00 | 2.00
U1 | R1-3V3 | 56.7625 | 17.3600 | 3V3 | 1.00 | 2.00
U1 | L2-GND | 31.2375 | 19.8800 | GND | 1.00 | 2.00
U1 | R2-GND | 56.7625 | 19.8800 | GND | 1.00 | 2.00
U1 | L3-D13 | 31.2375 | 22.4000 | NC | 1.00 | 2.00
U1 | R3-D15 | 56.7625 | 22.4000 | NC | 1.00 | 2.00
U1 | L4-D12 | 31.2375 | 24.9200 | NC | 1.00 | 2.00
U1 | R4-D2 | 56.7625 | 24.9200 | NC | 1.00 | 2.00
U1 | L5-D14 | 31.2375 | 27.4400 | NC | 1.00 | 2.00
U1 | R5-D4 | 56.7625 | 27.4400 | NC | 1.00 | 2.00
U1 | L6-D27 | 31.2375 | 29.9600 | HALL | 1.00 | 2.00
U1 | R6-RX2 | 56.7625 | 29.9600 | NC | 1.00 | 2.00
U1 | L7-D26 | 31.2375 | 32.4800 | NC | 1.00 | 2.00
U1 | R7-TX2 | 56.7625 | 32.4800 | NC | 1.00 | 2.00
U1 | L8-D25 | 31.2375 | 35.0000 | ESC_PWM_3V3 | 1.00 | 2.00
U1 | R8-D5 | 56.7625 | 35.0000 | NC | 1.00 | 2.00
U1 | L9-D33 | 31.2375 | 37.5200 | NC | 1.00 | 2.00
U1 | R9-D18 | 56.7625 | 37.5200 | DATA_A_3V3 | 1.00 | 2.00
U1 | L10-D32 | 31.2375 | 40.0400 | NC | 1.00 | 2.00
U1 | R10-D19 | 56.7625 | 40.0400 | CLOCK_A_3V3 | 1.00 | 2.00
U1 | L11-D35 | 31.2375 | 42.5600 | NC | 1.00 | 2.00
U1 | R11-D21 | 56.7625 | 42.5600 | NC | 1.00 | 2.00
U1 | L12-D34 | 31.2375 | 45.0800 | NC | 1.00 | 2.00
U1 | R12-RX0 | 56.7625 | 45.0800 | NC | 1.00 | 2.00
U1 | L13-VN | 31.2375 | 47.6000 | NC | 1.00 | 2.00
U1 | R13-TX0 | 56.7625 | 47.6000 | NC | 1.00 | 2.00
U1 | L14-VP | 31.2375 | 50.1200 | NC | 1.00 | 2.00
U1 | R14-D22 | 56.7625 | 50.1200 | CLOCK_B_3V3 | 1.00 | 2.00
U1 | L15-EN | 31.2375 | 52.6400 | NC | 1.00 | 2.00
U1 | R15-D23 | 56.7625 | 52.6400 | DATA_B_3V3 | 1.00 | 2.00
U4 | 1 | 73.1900 | 18.0000 | GND | 1.00 | 2.00
U4 | 2 | 73.1900 | 20.5400 | DATA_A_3V3 | 1.00 | 2.00
U4 | 3 | 73.1900 | 23.0800 | DATA_A_BUF | 1.00 | 2.00
U4 | 4 | 73.1900 | 25.6200 | GND | 1.00 | 2.00
U4 | 5 | 73.1900 | 28.1600 | CLOCK_A_3V3 | 1.00 | 2.00
U4 | 6 | 73.1900 | 30.7000 | CLOCK_A_BUF | 1.00 | 2.00
U4 | 7 | 73.1900 | 33.2400 | GND | 1.00 | 2.00
U4 | 8 | 80.8100 | 33.2400 | DATA_B_BUF | 1.00 | 2.00
U4 | 9 | 80.8100 | 30.7000 | DATA_B_3V3 | 1.00 | 2.00
U4 | 10 | 80.8100 | 28.1600 | GND | 1.00 | 2.00
U4 | 11 | 80.8100 | 25.6200 | CLOCK_B_BUF | 1.00 | 2.00
U4 | 12 | 80.8100 | 23.0800 | CLOCK_B_3V3 | 1.00 | 2.00
U4 | 13 | 80.8100 | 20.5400 | GND | 1.00 | 2.00
U4 | 14 | 80.8100 | 18.0000 | 5V | 1.00 | 2.00
U2-MP1584 | IN- | 7.0000 | 60.0000 | GND | 1.30 | 3.40
U2-MP1584 | IN+ | 20.0000 | 60.0000 | VBAT | 1.30 | 3.40
U2-MP1584 | OUT- | 7.0000 | 44.0000 | GND | 1.30 | 3.40
U2-MP1584 | OUT+ | 20.0000 | 44.0000 | 5V | 1.30 | 3.40
J_A | 1 | 105.0000 | 10.0000 | 5V | 1.00 | 2.00
J_A | 2 | 105.0000 | 12.5400 | GND | 1.00 | 2.00
J_A | 3 | 105.0000 | 15.0800 | DATA_A | 1.00 | 2.00
J_A | 4 | 105.0000 | 17.6200 | CLOCK_A | 1.00 | 2.00
J_B | 1 | 105.0000 | 51.5000 | 5V | 1.00 | 2.00
J_B | 2 | 105.0000 | 54.0400 | GND | 1.00 | 2.00
J_B | 3 | 105.0000 | 56.5800 | DATA_B | 1.00 | 2.00
J_B | 4 | 105.0000 | 59.1200 | CLOCK_B | 1.00 | 2.00
J_HALL | 1 | 67.0000 | 62.0000 | GND | 1.00 | 2.00
J_HALL | 2 | 67.0000 | 64.5400 | 3V3 | 1.00 | 2.00
J_HALL | 3 | 67.0000 | 67.0800 | HALL | 1.00 | 2.00
J_RING | 1 | 7.0000 | 67.0000 | VBAT | 1.00 | 2.00
J_RING | 2 | 9.5400 | 67.0000 | VBAT | 1.00 | 2.00
J_RING | 3 | 12.0800 | 67.0000 | GND | 1.00 | 2.00
J_RING | 4 | 14.6200 | 67.0000 | GND | 1.00 | 2.00
J_RING | 5 | 17.1600 | 67.0000 | ESC_PWM | 1.00 | 2.00
J_RING | 6 | 19.7000 | 67.0000 | SPARE | 1.00 | 2.00
R1 | 1 | 61.3800 | 23.0800 | DATA_A | 1.00 | 2.00
R1 | 2 | 69.0000 | 23.0800 | DATA_A_BUF | 1.00 | 2.00
R2 | 1 | 61.3800 | 30.7000 | CLOCK_A | 1.00 | 2.00
R2 | 2 | 69.0000 | 30.7000 | CLOCK_A_BUF | 1.00 | 2.00
R3 | 1 | 87.0000 | 38.3200 | DATA_B_BUF | 1.00 | 2.00
R3 | 2 | 94.6200 | 38.3200 | DATA_B | 1.00 | 2.00
R4 | 1 | 87.0000 | 45.9400 | CLOCK_B_BUF | 1.00 | 2.00
R4 | 2 | 94.6200 | 45.9400 | CLOCK_B | 1.00 | 2.00
R5 | 1 | 24.0000 | 61.5000 | ESC_PWM_3V3 | 1.00 | 2.00
R5 | 2 | 31.6200 | 61.5000 | ESC_PWM | 1.00 | 2.00
R6 | 1 | 59.5000 | 59.0000 | 3V3 | 1.00 | 2.00
R6 | 2 | 67.1200 | 59.0000 | HALL | 1.00 | 2.00
C3 | 1 | 84.0000 | 18.0000 | 5V | 1.00 | 2.00
C3 | 2 | 84.0000 | 21.0000 | GND | 1.00 | 2.00
C4 | 1 | 100.0000 | 8.0000 | 5V | 1.00 | 2.80
C4 | 2 | 100.0000 | 12.0000 | GND | 1.00 | 2.80
C5 | 1 | 100.0000 | 50.0000 | 5V | 1.00 | 2.80
C5 | 2 | 100.0000 | 54.0000 | GND | 1.00 | 2.80

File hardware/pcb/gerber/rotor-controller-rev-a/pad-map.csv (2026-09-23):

ref | pin | x_mm | y_mm | net | drill_mm | pad_mm
U1 | L1-VIN | 10.2375 | 16.1850 | 5V | 1.10 | 2.00
U1 | R1-3V3 | 35.7625 | 16.1850 | 3V3 | 1.10 | 2.00
U1 | L2-GND | 10.2375 | 18.7050 | GND | 1.10 | 2.00
U1 | R2-GND | 35.7625 | 18.7050 | GND | 1.10 | 2.00
U1 | L3-D13 | 10.2375 | 21.2250 | NC | 1.10 | 2.00
U1 | R3-D15 | 35.7625 | 21.2250 | NC | 1.10 | 2.00
U1 | L4-D12 | 10.2375 | 23.7450 | NC | 1.10 | 2.00
U1 | R4-D2 | 35.7625 | 23.7450 | NC | 1.10 | 2.00
U1 | L5-D14 | 10.2375 | 26.2650 | NC | 1.10 | 2.00
U1 | R5-D4 | 35.7625 | 26.2650 | NC | 1.10 | 2.00
U1 | L6-D27 | 10.2375 | 28.7850 | HALL | 1.10 | 2.00
U1 | R6-RX2 | 35.7625 | 28.7850 | NC | 1.10 | 2.00
U1 | L7-D26 | 10.2375 | 31.3050 | NC | 1.10 | 2.00
U1 | R7-TX2 | 35.7625 | 31.3050 | NC | 1.10 | 2.00
U1 | L8-D25 | 10.2375 | 33.8250 | ESC_PWM_3V3 | 1.10 | 2.00
U1 | R8-D5 | 35.7625 | 33.8250 | NC | 1.10 | 2.00
U1 | L9-D33 | 10.2375 | 36.3450 | NC | 1.10 | 2.00
U1 | R9-D18 | 35.7625 | 36.3450 | DATA_A_3V3 | 1.10 | 2.00
U1 | L10-D32 | 10.2375 | 38.8650 | NC | 1.10 | 2.00
U1 | R10-D19 | 35.7625 | 38.8650 | CLOCK_A_3V3 | 1.10 | 2.00
U1 | L11-D35 | 10.2375 | 41.3850 | NC | 1.10 | 2.00
U1 | R11-D21 | 35.7625 | 41.3850 | NC | 1.10 | 2.00
U1 | L12-D34 | 10.2375 | 43.9050 | NC | 1.10 | 2.00
U1 | R12-RX0 | 35.7625 | 43.9050 | NC | 1.10 | 2.00
U1 | L13-VN | 10.2375 | 46.4250 | NC | 1.10 | 2.00
U1 | R13-TX0 | 35.7625 | 46.4250 | NC | 1.10 | 2.00
U1 | L14-VP | 10.2375 | 48.9450 | NC | 1.10 | 2.00
U1 | R14-D22 | 35.7625 | 48.9450 | CLOCK_B_3V3 | 1.10 | 2.00
U1 | L15-EN | 10.2375 | 51.4650 | NC | 1.10 | 2.00
U1 | R15-D23 | 35.7625 | 51.4650 | DATA_B_3V3 | 1.10 | 2.00
U4 | 1 | 48.1900 | 22.0000 | GND | 1.10 | 2.00
U4 | 2 | 48.1900 | 24.5400 | DATA_A_3V3 | 1.10 | 2.00
U4 | 3 | 48.1900 | 27.0800 | DATA_A_BUF | 1.10 | 2.00
U4 | 4 | 48.1900 | 29.6200 | GND | 1.10 | 2.00
U4 | 5 | 48.1900 | 32.1600 | CLOCK_A_3V3 | 1.10 | 2.00
U4 | 6 | 48.1900 | 34.7000 | CLOCK_A_BUF | 1.10 | 2.00
U4 | 7 | 48.1900 | 37.2400 | GND | 1.10 | 2.00
U4 | 8 | 55.8100 | 37.2400 | DATA_B_BUF | 1.10 | 2.00
U4 | 9 | 55.8100 | 34.7000 | DATA_B_3V3 | 1.10 | 2.00
U4 | 10 | 55.8100 | 32.1600 | GND | 1.10 | 2.00
U4 | 11 | 55.8100 | 29.6200 | CLOCK_B_BUF | 1.10 | 2.00
U4 | 12 | 55.8100 | 27.0800 | CLOCK_B_3V3 | 1.10 | 2.00
U4 | 13 | 55.8100 | 24.5400 | GND | 1.10 | 2.00
U4 | 14 | 55.8100 | 22.0000 | 5V | 1.10 | 2.00
J_A | 1 | 84.0000 | 18.0000 | 5V | 1.10 | 2.00
J_A | 2 | 84.0000 | 20.5400 | GND | 1.10 | 2.00
J_A | 3 | 84.0000 | 23.0800 | DATA_A | 1.10 | 2.00
J_A | 4 | 84.0000 | 25.6200 | CLOCK_A | 1.10 | 2.00
J_B | 1 | 84.0000 | 38.0000 | 5V | 1.10 | 2.00
J_B | 2 | 84.0000 | 40.5400 | GND | 1.10 | 2.00
J_B | 3 | 84.0000 | 43.0800 | DATA_B | 1.10 | 2.00
J_B | 4 | 84.0000 | 45.6200 | CLOCK_B | 1.10 | 2.00
J_RING | 1 | 4.0000 | 60.0000 | 5V | 1.10 | 2.00
J_RING | 2 | 6.5400 | 60.0000 | 5V | 1.10 | 2.00
J_RING | 3 | 9.0800 | 60.0000 | GND | 1.10 | 2.00
J_RING | 4 | 11.6200 | 60.0000 | GND | 1.10 | 2.00
J_RING | 5 | 14.1600 | 60.0000 | ESC_PWM | 1.10 | 2.00
J_RING | 6 | 16.7000 | 60.0000 | NC | 1.10 | 2.00
J_HALL | 1 | 44.0000 | 4.5000 | GND | 1.10 | 2.00
J_HALL | 2 | 46.5400 | 4.5000 | 3V3 | 1.10 | 2.00
J_HALL | 3 | 49.0800 | 4.5000 | HALL | 1.10 | 2.00
R1 | 1 | 69.0000 | 14.0000 | DATA_A_BUF | 1.10 | 2.00
R1 | 2 | 76.6200 | 14.0000 | DATA_A | 1.10 | 2.00
R2 | 1 | 69.0000 | 18.0000 | CLOCK_A_BUF | 1.10 | 2.00
R2 | 2 | 76.6200 | 18.0000 | CLOCK_A | 1.10 | 2.00
R3 | 1 | 69.0000 | 37.0000 | DATA_B_BUF | 1.10 | 2.00
R3 | 2 | 76.6200 | 37.0000 | DATA_B | 1.10 | 2.00
R4 | 1 | 69.0000 | 30.0000 | CLOCK_B_BUF | 1.10 | 2.00
R4 | 2 | 76.6200 | 30.0000 | CLOCK_B | 1.10 | 2.00
R5 | 1 | 24.0000 | 55.0000 | ESC_PWM_3V3 | 1.10 | 2.00
R5 | 2 | 31.6200 | 55.0000 | ESC_PWM | 1.10 | 2.00
R6 | 1 | 36.0000 | 10.0000 | 3V3 | 1.10 | 2.00
R6 | 2 | 43.6200 | 10.0000 | HALL | 1.10 | 2.00
C3 | 1 | 58.5000 | 24.0000 | 5V | 1.10 | 2.00
C3 | 2 | 61.0400 | 24.0000 | GND | 1.10 | 2.00
C4 | 1 | 82.0000 | 8.0000 | 5V | 1.00 | 2.20
C4 | 2 | 82.0000 | 13.0000 | GND | 1.00 | 2.20
C5 | 1 | 82.0000 | 50.0000 | 5V | 1.00 | 2.20
C5 | 2 | 82.0000 | 54.0000 | GND | 1.00 | 2.20
V1 | 1 | 38.0000 | 48.9450 | CLOCK_B_3V3 | 0.40 | 0.90
V2 | 1 | 38.0000 | 18.0000 | CLOCK_B_3V3 | 0.40 | 0.90

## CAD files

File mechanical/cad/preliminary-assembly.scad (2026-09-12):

// Preliminary two-blade POV layout.
// Concept only: dimensions marked as placeholders must be measured before fabrication.

$fn = 96;

view_mode = "assembly"; // assembly, rotor, guard
show_led_markers = true;
show_guard_envelope = true;

// Confirmed project limits
blade_count = 2;
blade_active_length = 150;
led_count_per_blade = 21;

// Placeholder dimensions: replace only after physical measurement
blade_root_offset = 28;
blade_width = 22;
blade_thickness = 1.5;
beam_width = 16;
beam_thickness = 3;
hub_outer_diameter = 36;
hub_height = 10;
shaft_placeholder_diameter = 3.2;
motor_placeholder_diameter = 28;
motor_placeholder_height = 30;
slip_ring_placeholder_diameter = 22;
slip_ring_placeholder_height = 18;
electronics_envelope = [58, 32, 13];
guard_clearance = 25;
guard_height = 48;

rotor_radius = blade_root_offset + blade_active_length;
guard_radius = rotor_radius + guard_clearance;
beam_length = 2 * rotor_radius;

module motor_placeholder() {
    color([0.25, 0.25, 0.28])
        translate([0, 0, -motor_placeholder_height])
            cylinder(d=motor_placeholder_diameter, h=motor_placeholder_height);
}

module slip_ring_placeholder() {
    color([0.75, 0.55, 0.18])
        translate([0, 0, -8])
            difference() {
                cylinder(d=slip_ring_placeholder_diameter,
                         h=slip_ring_placeholder_height);
                translate([0, 0, -1])
                    cylinder(d=shaft_placeholder_diameter + 1,
                             h=slip_ring_placeholder_height + 2);
            }
}

module load_bearing_beam() {
    color([0.18, 0.20, 0.23])
        translate([0, 0, beam_thickness / 2])
            cube([beam_length, beam_width, beam_thickness], center=true);
}

module blade_plate(side = 1) {
    blade_center = side * (blade_root_offset + blade_active_length / 2);

    color([0.08, 0.35, 0.18])
        translate([blade_center, 0, beam_thickness + blade_thickness / 2])
            cube([blade_active_length, blade_width, blade_thickness], center=true);

    if (show_led_markers) {
        for (index = [0 : led_count_per_blade - 1]) {
            led_x = side * (
                blade_root_offset
                + 4
                + index * (blade_active_length - 8) / (led_count_per_blade - 1)
            );
            color([0.95, 0.82, 0.20])
                translate([led_x, 0, beam_thickness + blade_thickness])
                    cylinder(d=3.2, h=0.7);
        }
    }
}

module hub_placeholder() {
    color([0.45, 0.47, 0.50])
        difference() {
            cylinder(d=hub_outer_diameter, h=hub_height);
            translate([0, 0, -1])
                cylinder(d=shaft_placeholder_diameter, h=hub_height + 2);
        }
}

module electronics_placeholder() {
    color([0.05, 0.25, 0.55, 0.70])
        translate([
            -electronics_envelope[0] / 2,
            -electronics_envelope[1] / 2,
            hub_height + 2
        ])
            cube(electronics_envelope);
}

module rotor_concept() {
    load_bearing_beam();
    blade_plate(-1);
    blade_plate(1);
    hub_placeholder();
    slip_ring_placeholder();
    electronics_placeholder();
}

module guard_envelope() {
    color([0.35, 0.65, 0.90, 0.10])
        translate([0, 0, -motor_placeholder_height])
            cylinder(r=guard_radius,
                     h=guard_height + motor_placeholder_height);
}

if (view_mode == "rotor") {
    rotor_concept();
} else if (view_mode == "guard") {
    guard_envelope();
} else {
    motor_placeholder();
    rotor_concept();
    if (show_guard_envelope) {
        guard_envelope();
    }
}

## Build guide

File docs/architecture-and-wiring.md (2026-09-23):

# Архитектура и назначение выводов

## Разделение системы

Неподвижная часть: Li-Po 3S, предохранитель, выключатель, ESC и A2212. Вращающаяся часть Rev B: MP1584, ESP32, KY-003, SN74AHCT125 и две лопасти APA102.

```mermaid
flowchart LR
  BAT[Li-Po 3S] --> F1[Главный предохранитель]
  F1 --> SW[Выключатель]
  SW --> ESC[ESC 30 A]
  ESC --> M[A2212 1000KV]
  SW --> F2[Предохранитель логики]
  F2 --> SR[Кольцо: 1+2 = VBAT; 3+4 = GND]
  SR --> BUCK[MP1584 5 V на роторе]
  BUCK --> ESP[ESP32 на роторе]
  ESP --> BUF[SN74AHCT125]
  BUF --> A[APA102 A: 20 LED default]
  BUF --> B[APA102 B: 20 LED default]
  H[KY-003] --> ESP
  ESP -->|GPIO25, канал 5| ESC
```

## Шестиканальное кольцо

| Канал | Предварительное назначение | Условие |
|---:|---|---|
| 1 | VBAT_ROTOR | Параллельно каналу 2 только после проверки каждого канала |
| 2 | VBAT_ROTOR | То же |
| 3 | GND_ROTOR | Параллельно каналу 4 после проверки |
| 4 | GND_ROTOR | То же |
| 5 | ESC_PWM | GPIO25 → 220 Ом → роторный конец → статорный ESC |
| 6 | Резерв | Оба конца изолировать |

Параллельные контакты могут делить ток неравномерно. Окончательное разрешение зависит от сопротивления каналов и нагрузочного теста.

## SN74AHCT125N

| Канал микросхемы | Вход | Выход | Назначение |
|---|---:|---:|---|
| 1 | pin 2 | pin 3 | GPIO18 → DATA A |
| 2 | pin 5 | pin 6 | GPIO19 → CLOCK A |
| 3 | pin 9 | pin 8 | GPIO23 → DATA B |
| 4 | pin 12 | pin 11 | GPIO22 → CLOCK B |

Pins 1, 4, 10 и 13 (`OE`) соединить с GND. Pin 14 → 5 В, pin 7 → GND. Конденсатор 100 нФ установить непосредственно между pins 14 и 7. На каждом из четырёх выходов нужен последовательный резистор 330–470 Ом.

## Питание лопастей

Питание обеих лопастей разводится звездой от центральной точки ротора. Нельзя пропускать питание второй лопасти через первую. У входа каждой ленты требуется локальная развязка; номиналы уточняются после измерения пульсаций и длины проводов.

## Разъёмы

Назначение контактов `JH1`, `JLA`, `JLB` и `JESC`, проектные цвета и критерии качества обжима собраны в [карте разъёмов](../hardware/connectors-and-wire-colors.md). Машиночитаемая копия распиновки находится в `hardware/connector-pinout.csv`.

XH-совместимые корпуса не применяются в силовой цепи аккумулятора и мотора. Возможность их использования для питания светодиодных лопастей требует отдельного нагрузочного теста.

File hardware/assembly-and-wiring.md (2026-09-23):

# Монтаж и соединения

Документ задаёт проектную схему соединений. Нумерация контактов модулей и цвета жил кольца подтверждаются на фактических деталях до пайки.

## Неподвижная часть

| Откуда | Куда | Провод | Проверка перед соединением |
|---|---|---|---|
| Li-Po `+` | F1 → выключатель → ESC `+` | 14–16 AWG красный | Полярность, номинал F1, выключатель DC |
| Li-Po `−` | ESC `−` | 14–16 AWG чёрный | Общая земля силовой части |
| После выключателя | F2 → кольцо CH1 и CH2 | Две отдельные жилы | VBAT отсутствует при выключенном выключателе |
| Li-Po `−` | Кольцо CH3 и CH4 | Две отдельные жилы | Полярность и непрерывность земли |
| ESC signal | Кольцо CH5 | 26 AWG | BEC-красный провод не соединён |
| Драйвер звука | Кольцо CH6 | 26 AWG | Только после выбора зуммера |

## Вращающаяся часть

| Откуда | Куда | Назначение |
|---|---|---|
| CH1 + CH2 | MP1584 `IN+`, шина `VBAT_ROTOR` | Параллельно после прозвонки одинаковых каналов |
| CH3 + CH4 | Шина `GND_ROTOR` | Общая земля ротора |
| `GND_ROTOR` | MP1584 `IN−` и `OUT−` | Общая земля преобразователя |
| MP1584 `OUT+`, шина `+5V_ROTOR` | ESP32 `VIN`, SN74AHCT125 VCC, обе APA102 | Звёздное питание; не в `3V3` |
| `GND_ROTOR` | Все GND | Единая точка около распределения питания |
| GPIO18 | U4 канал 1 → 330–470 Ом → APA102 A DI | DATA A |
| GPIO19 | U4 канал 2 → 330–470 Ом → APA102 A CI | CLOCK A |
| GPIO23 | U4 канал 3 → 330–470 Ом → APA102 B DI | DATA B |
| GPIO22 | U4 канал 4 → 330–470 Ом → APA102 B CI | CLOCK B |
| GPIO27 | KY-003 OUT | Hall; OUT предварительно измеряется |
| ESP32 3V3 | KY-003 VCC | Не питать Hall от 5 В без проверки модуля |
| GPIO25 | 220 Ом → CH5 → ESC signal | PWM 50 Гц |

Все четыре `/OE` SN74AHCT125 соединяются с GND. Конденсатор 100 нФ размещается непосредственно у выводов 14 и 7 буфера. Электролиты у лопастей устанавливаются с проверенной полярностью.

## Порядок первого включения

1. Не подключать аккумулятор, ESC и мотор.
2. Прозвонить отсутствие короткого замыкания между 5 В и GND.
3. Настроить MP1584 отдельно на 5,00 В.
4. Подключить эквивалент нагрузки к MP1584, затем подать VBAT через кольцо; повторить измерения на входе и выходе преобразователя.
5. Проверить ESP32 от USB отдельно.
6. Проверить Hall от 3,3 В.
7. Проверить одну APA102 при неподвижной конструкции, затем вторую.
8. Проверить две ветви вместе с программным лимитом яркости.
9. Проверить PWM осциллографом без мотора.

JST-XH-подобные корпуса не надеваются непосредственно на гребёнку ESP32, если нужные выводы расположены не подряд. Для финальной сборки применяется переходная плата или закреплённый жгут с индивидуально изолированными контактами.

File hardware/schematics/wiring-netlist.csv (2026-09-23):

from | to | net | note
BATTERY_SWITCHED+ | RING_1+RING_2 | VBAT_STATOR | parallel only after channel validation
BATTERY- | RING_3+RING_4 | GND_STATOR | common ground
RING_1+RING_2 | MP1584_IN+ | VBAT_ROTOR | rotor side
RING_3+RING_4 | MP1584_IN-+MP1584_OUT- | GND_ROTOR | common rotor ground
MP1584_OUT+ | ESP32_VIN | 5V_ROTOR | rotor side
MP1584_OUT+ | SN74AHCT125_PIN14 | 5V_ROTOR | 100 nF to pin 7
MP1584_OUT+ | APA102_A_5V+APA102_B_5V | 5V_ROTOR | star wiring
MP1584_OUT- | ESP32_GND+SN74AHCT125_PIN7+KY003_GND+APA102_GND | GND_ROTOR | common rotor ground
ESP32_GPIO18 | SN74AHCT125_PIN2 | LED_A_DATA_3V3
SN74AHCT125_PIN3 | R_DATA_A | LED_A_DATA_5V | 330-470 ohm
R_DATA_A | APA102_A_DI | LED_A_DATA_IN
ESP32_GPIO19 | SN74AHCT125_PIN5 | LED_A_CLOCK_3V3
SN74AHCT125_PIN6 | R_CLOCK_A | LED_A_CLOCK_5V | 330-470 ohm
R_CLOCK_A | APA102_A_CI | LED_A_CLOCK_IN
ESP32_GPIO23 | SN74AHCT125_PIN9 | LED_B_DATA_3V3
SN74AHCT125_PIN8 | R_DATA_B | LED_B_DATA_5V | 330-470 ohm
R_DATA_B | APA102_B_DI | LED_B_DATA_IN
ESP32_GPIO22 | SN74AHCT125_PIN12 | LED_B_CLOCK_3V3
SN74AHCT125_PIN11 | R_CLOCK_B | LED_B_CLOCK_5V | 330-470 ohm
R_CLOCK_B | APA102_B_CI | LED_B_CLOCK_IN
ESP32_3V3 | KY003_VCC | 3V3_HALL
KY003_OUT | ESP32_GPIO27 | HALL_OUT | must remain <=3.3 V
ESP32_GPIO25 | R_PWM | ESC_PWM_ROTOR | 220 ohm
R_PWM | RING_5 | ESC_PWM | to stationary ESC signal
SN74AHCT125_PIN1+PIN4+PIN10+PIN13 | GND_ROTOR | BUFFER_ENABLE | all OE low

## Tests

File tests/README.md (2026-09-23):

# Стендовые проверки

Результаты всех физических измерений заносятся в `bring-up-results.md`. Значение `PASS` допускается только после фактической проверки; ожидаемое или расчётное значение результатом не считается.

## Протоколы

1. [Приёмка новых компонентов](components-intake-checklist.md)
2. [ESP32 и общий порядок сборки](../docs/bring-up-plan.md)
3. [Датчик Холла KY-003](ky-003-protocol.md)
4. [Понижающий преобразователь MP1584](mp1584-protocol.md)
5. [Преобразователь уровней SN74AHCT125](sn74ahct125-protocol.md)
6. [Шестиканальное кольцо](slip-ring-protocol.md)
7. [Две APA102 без вращения](apa102-static-protocol.md)
8. [Сигнал ESC без мотора](esc-signal-protocol.md)

Перед каждой проверкой выполняются визуальный осмотр, проверка полярности и контроль отсутствия короткого замыкания. Мотор, ESC и ротор остаются отключёнными.

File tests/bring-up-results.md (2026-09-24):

# Результаты испытаний

## 2026-09-11 — ESP32 без периферии

| Проверка | Результат | Статус |
|---|---|---|
| USB-UART | CP2102, COM5 | PASS |
| Напряжение 3V3–GND | 3,30 В DC | PASS |
| Загрузка PlatformIO | Успешно, контрольная сумма подтверждена | PASS |
| Serial 115200 | Стартовые сообщения получены | PASS |
| `PING` | `PONG` | PASS |
| `SIMRPM 1200` | 50000 мкс | PASS |
| `PWM 1500` при блокировке | Остался 1000 мкс | PASS |
| BLE | `ESP32-POV-Test` запущен | PASS по журналу ESP32; проверка через BLE-приложение ещё не выполнена |

Мотор, ESC, Hall и LED во время проверки не подключались.

## 2026-09-21 — KY-003 на GPIO27

Проверка выполнена при питании ESP32 от USB. KY-003 подключён к `3V3`, `GND` и GPIO27. Между `S` и `3V3` установлен внешний резистор подтяжки 10 кОм.

| Измерение | Результат | Статус |
|---|---|---|
| VCC–GND | 3,30 В | PASS |
| OUT без внешней подтяжки | 1,8 В | Неприемлемо как надёжный HIGH |
| OUT без магнита с подтяжкой 10 кОм | 3,29 В | PASS |
| OUT с неактивным полюсом магнита | 3,29 В | PASS |
| OUT с активным полюсом, LED горит | 0,01 В | PASS |
| Один полный поднос и удаление магнита | Счётчик изменился с 0 на 1 | PASS |
| Serial | `PULSE HALL count=1` | PASS |

Датчик униполярный: срабатывание получено только одним полюсом магнита. Резистор 10 кОм требуется сохранить в окончательном жгуте.

## 2026-09-21 — приёмка питания и APA102

Проверки выполнены без подачи питания на ленту, MP1584, ESC и мотор.

| Проверка | Результат | Статус |
|---|---|---|
| Li-Po 3S, силовой разъём | 11,8 В | PASS по общему напряжению; отдельные банки не проверены |
| Маркировка Li-Po | 1500 мА·ч, 11,1 В, 45C, XT60 | Подтверждено |
| Маркировка ESC | 30 А, 2–4S, BEC 5 В/2 А | Подтверждено |
| Маркировка двигателя | A2212/13T 1000KV | Подтверждено |
| Буфер | SN74AHCT125N, DIP-14 | Подтверждено |
| Преобразователь | MP1584EN | Получен, электрически не проверен |
| Геометрия APA102 | 20 LED занимают 140 мм | PASS для первой сборки |
| Направление APA102 | Стрелки идут от установленного разъёма вдоль ленты | Входной конец определён |
| Сопротивление `5V–G` | 787 Ом | Прямого короткого замыкания не обнаружено |
| Отдельный красный провод | Прозванивается с `5V` | Подтверждено |
| Отдельный чёрный провод | Прозванивается с `G`, показание `001` | Подтверждено |
| Отдельный чёрный провод — `5V` | Около 800 Ом | Прямого соединения нет |
| Разъём: белый провод | `G` | Подтверждено |
| Разъём: красный провод | `5V` | Подтверждено |
| Разъём: синий и зелёный | `CI` и `DI` | Порядок не подтверждён; проверить под ограниченным питанием |

Лента не разрезалась. Сигнальные площадки после первого APA102 не обязаны прозваниваться с входным разъёмом, поскольку DATA и CLOCK проходят через каждый светодиодный контроллер.

## 2026-09-23 — итог стендовой проверки компонентов

По сообщению сборщика, все имеющиеся компоненты, кроме ещё не полученного токосъёмного кольца, прошли предусмотренные для них автономные стендовые проверки. Неисправностей, нестабильной работы и отклонений от критериев протоколов не обнаружено.

| Узел | Итог | Статус |
|---|---|---|
| ESP32 | Загрузка, питание и интерфейсы работают | PASS |
| KY-003 | Уровни и импульс GPIO27 корректны | PASS |
| MP1584 | Настройка выхода и нагрузочная проверка пройдены | PASS, сообщено сборщиком |
| SN74AHCT125 | Четыре канала преобразования уровней работают | PASS, сообщено сборщиком |
| APA102, лопасть A | DATA/CLOCK, цвета и все 20 LED работают | PASS, сообщено сборщиком |
| APA102, лопасть B | DATA/CLOCK, цвета и все 20 LED работают | PASS, сообщено сборщиком |
| Две APA102 одновременно | Сбросов и выявленных проблем нет | PASS, сообщено сборщиком |
| ESC, прямое подключение без кольца | Предусмотренная автономная проверка пройдена | PASS, сообщено сборщиком |
| Мотор без установленного ротора | Предусмотренная автономная проверка пройдена | PASS, сообщено сборщиком |
| Токосъёмное кольцо | Деталь отсутствует | ОЖИДАЕТ |

Числовые журналы, осциллограммы, ток и температура для этой серии испытаний в репозиторий не переданы. Поэтому запись фиксирует сообщённый результат, но не заменяет измерительные данные. Испытания собранного ротора, балансировка и POV-синхронизация этой записью не закрываются.

## 2026-09-24 — сборка итоговой проектной прошивки

| Конфигурация | Результат | Статус |
|---|---|---|
| `esp32dev`, безопасные блокировки включены | RAM 47 292 байт; flash 1 154 685 байт | PASS |
| `esp32dev-final`, POV и проектный автомат ESC скомпилированы | RAM 47 340 байт; flash 1 156 669 байт | PASS |

Прошивка не загружалась в ESP32. ARM, heartbeat, аварийные остановы, сохранение изображения и вывод APA102 в этой версии аппаратно не проверялись.

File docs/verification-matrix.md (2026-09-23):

# Матрица проверки проекта

`PASS` ставится только после фактического испытания. Расчёт или успешная компиляция не заменяют аппаратную проверку.

| ID | Объект | Проверка | Критерий | Состояние | Доказательство |
|---|---|---|---|---|---|
| V-01 | ESP32 | Питание от USB и Serial | 3,3 В; стабильная загрузка | PASS | `tests/bring-up-results.md` |
| V-02 | KY-003 | Питание 3,3 В, магнит с обеих сторон | OUT ≤3,3 В; устойчивое переключение | PASS | `tests/bring-up-results.md` |
| V-03 | Hall + прошивка | Контрольный проход магнита | Один импульс на проход | PASS | `tests/bring-up-results.md` |
| V-04 | MP1584 без нагрузки | Настройка выхода | 5,00 В до подключения электроники | PASS, сообщено сборщиком | `tests/bring-up-results.md` |
| V-05 | MP1584 под нагрузкой | 15 минут на эквиваленте | ≥4,75 В; без опасного нагрева | PASS, сообщено сборщиком | `tests/bring-up-results.md`; числовой журнал не приложен |
| V-06 | Кольцо | Прозвонка при медленном вращении | Нет обрывов и замыканий | Ожидает | `hardware/slip-ring-pinout.md` |
| V-07 | Кольцо под нагрузкой | Питание через 2+2 жилы | На роторе ≥4,70 В; нагрев допустим | Ожидает | Таблица измерений |
| V-08 | SN74AHCT125 | Уровни четырёх каналов | Корректные логические 0/5 В | PASS, сообщено сборщиком | `tests/bring-up-results.md`; числовой журнал не приложен |
| V-09 | APA102 A | DATA/CLOCK без вращения | Все LED и цвета корректны | PASS, сообщено сборщиком | `tests/bring-up-results.md` |
| V-10 | APA102 B | DATA/CLOCK без вращения | Все LED и цвета корректны | PASS, сообщено сборщиком | `tests/bring-up-results.md` |
| V-11 | Две лопасти | Одновременный статический тест | Нет сбросов; ток в пределах лимита | PASS, сообщено сборщиком | `tests/bring-up-results.md`; числовой журнал не приложен |
| V-12 | ESC PWM через кольцо | Осциллограф без мотора | 50 Гц; 1000 мкс в SAFE | Частично: прямой тест PASS, кольцо ожидается | `tests/bring-up-results.md` |
| V-13 | Мотор без ротора | Плавный тест в кожухе | Управляемый RPM; аварийное отключение работает | Запрещено до готовности | Протокол моторного теста |
| V-14 | Ротор | Статическая балансировка | Нет устойчивого тяжёлого положения | Ожидает | Протокол балансировки |
| V-15 | Первый spin-test | Закрытый кожух, ступени RPM | Нет роста вибрации, смещения и нагрева | Запрещено до готовности | Протокол испытания |
| V-16 | POV-синхронизация | Тестовая сетка | Стабильная фаза; гашение при потере Hall | Ожидает | Видео и журнал |

## Допуск к моторным испытаниям

До V-13 и V-15 должны быть закрыты V-02–V-12 и V-14, установлен закрытый ударопрочный кожух, зафиксирован крепёж и проверено физическое аварийное отключение питания. Людей в плоскости ротора быть не должно.

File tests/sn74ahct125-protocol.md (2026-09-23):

# Проверка SN74AHCT125 без светодиодных лент

## Цель

Подтвердить преобразование четырёх сигналов ESP32 с 3,3 В до логических уровней, пригодных для APA102 при питании 5 В. APA102 и ESC во время этой проверки отключены.

## Схема стенда

| Вывод U4 | Подключение |
|---:|---|
| 1, 4, 10, 13 (`/OE`) | GND |
| 2 (`1A`) | GPIO18, DATA A |
| 3 (`1Y`) | контроль выхода DATA A |
| 5 (`2A`) | GPIO19, CLOCK A |
| 6 (`2Y`) | контроль выхода CLOCK A |
| 7 | GND |
| 8 (`3Y`) | контроль выхода DATA B |
| 9 (`3A`) | GPIO23, DATA B |
| 11 (`4Y`) | контроль выхода CLOCK B |
| 12 (`4A`) | GPIO22, CLOCK B |
| 14 | стабилизированные 5,00 В |

Керамический конденсатор 100 нФ устанавливается непосредственно между выводами 14 и 7. Земли источника 5 В и ESP32 объединяются. На время проверки выходы 3, 6, 8 и 11 не подключаются к APA102.

## Безопасная последовательность

1. При отключённом питании проверить ключ корпуса и нумерацию выводов DIP-14.
2. Проверить отсутствие короткого замыкания между выводами 14 и 7.
3. На лабораторном источнике установить `5,00 В`, ограничение тока `0,05 А`.
4. Подать питание только на U4 и убедиться, что микросхема не нагревается и источник не входит в ограничение.
5. Подключить общую землю ESP32 и по очереди подать на каждый вход устойчивые уровни 0 и 3,3 В.
6. Измерить соответствующий выход относительно GND.
7. Только после четырёх успешных каналов установить последовательные резисторы 330–470 Ом и подключать одну APA102-ветвь.

## Критерии

| Проверка | PASS |
|---|---|
| Потребление без нагрузки | Нет срабатывания ограничения 0,05 А и нагрева |
| Низкий уровень каждого выхода | Не выше 0,4 В |
| Высокий уровень каждого выхода | Не ниже 4,5 В при питании 5,00 В |
| Реакция каналов | Каждый выход повторяет только свой вход; соседние выходы не переключаются |

Обычный мультиметр подходит только для постоянных уровней. Форму импульсов DATA/CLOCK и выбросы на частоте SPI проверяют осциллографом или логическим анализатором; отсутствие такого прибора фиксируется отдельно и не заменяется визуальной оценкой LED.

## Основание выбора

- APA102: `VIH(min)=0,7×VDD`; при 5 В это 3,5 В.
- SN74AHCT125 при 4,5–5,5 В: `VIH(min)=2,0 В`, поэтому 3,3-вольтовый выход ESP32 распознаётся с запасом.
- 74HC125 не является эквивалентной заменой: его CMOS-порог не даёт такого запаса для 3,3 В.

Источники: [APA102 datasheet](https://cdn-shop.adafruit.com/product-files/2434/APA102_White_LED.pdf), [SN74AHCT125 datasheet](https://www.ti.com/lit/ds/symlink/sn74ahct125.pdf), [ESP32 datasheet](https://documentation.espressif.com/esp32_datasheet_en.pdf).

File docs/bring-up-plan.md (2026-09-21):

# План стендовой проверки и сборки

## Правило безопасности

Каждый следующий этап разрешён только после записи результатов предыдущего в `tests/bring-up-results.md`. Моторное питание остаётся отключённым до этапа 9.

## Этапы

1. **ESP32 без периферии** — завершено: 3,30 В, COM5, Serial/BLE, безопасный PWM.
2. **KY-003** — выполнить [`tests/ky-003-protocol.md`](../tests/ky-003-protocol.md): проверить распиновку, уровни OUT и один импульс на проход магнита.
3. **MP1584** — выполнить [`tests/mp1584-protocol.md`](../tests/mp1584-protocol.md): настроить 5,00 В и провести ступенчатый нагрузочный тест без электроники.
4. **SN74AHCT125** — проверить питание 5 В и четыре выходных канала без LED.
5. **Один APA102** — проверить DATA/CLOCK каждой будущей лопасти.
6. **Одна лопасть, 20 LED** — ограничить LED-ток до 0,50 А, контролировать 5 В и нагрев.
7. **Две лопасти, 40 LED без вращения** — ограничить LED-ток до 0,90 А суммарно.
8. **Кольцо** — прозвонка, сопротивление, нагрузочный тест 5 В и проверка PWM при ручном вращении.
9. **Мотор без ротора** — определить направление, ток и минимальные устойчивые обороты.
10. **Полная статическая сборка** — фиксация проводов, крепежа, статическая и динамическая балансировка.
11. **Первое вращение** — только внутри кожуха, без USB, с удалённым отключением и минимальной скоростью.

## Стоп-критерии

Немедленно отключить аккумулятор при росте вибрации, смещении крепежа, изгибе лопасти, касании кожуха, пропусках Hall, сбросах ESP32, 5 В ниже 4,70 В, нагреве кольца/проводов/DC-DC, неожиданном ускорении или нестабильном PWM.

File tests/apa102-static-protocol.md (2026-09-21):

# Статическая проверка двух APA102

ESC и мотор физически отключены. Лопасти не устанавливаются на мотор.

## Подготовка

1. Подтвердить стрелками направление `DI/CI → DO/CO`.
2. Посчитать LED и обновить `LEDS_PER_BLADE`.
3. Проверить полярность электролитов и 100 нФ у SN74AHCT125.
4. Соединить земли ESP32, буфера и питания LED.
5. При питании ESP32 от USB не подключать внешние 5 В к `VIN` ESP32.
6. Ограничить ток источника; начать с одной лопасти и минимальной яркости.

## Проверка сигналов до LED

Сборка с `POV_DISPLAY_ENABLED=1` допускается только при отключённых ESC и моторе. Двумя импульсами на GPIO27 задаётся период. Логическим анализатором проверяются DATA/CLOCK на GPIO18/19 и GPIO23/22, уровни после SN74AHCT125 и гашение при прекращении импульсов Hall.

## Последовательность

| Шаг | Подключение | Критерий |
|---|---|---|
| 1 | Только лопасть A, 1 LED | Цвета соответствуют, ток стабилен |
| 2 | Вся лопасть A | Нет пропусков, нагрева и сбросов |
| 3 | Только лопасть B | Аналогично A |
| 4 | Обе лопасти | Сетка различима, питание ≥4,75 В |
| 5 | Потеря Hall | Обе ветви гаснут |

Если перепутаны красный и синий, фиксируется реальный порядок цветов. Если не работает конец ленты, проверяются направление и число LED; количество не увеличивается вслепую.

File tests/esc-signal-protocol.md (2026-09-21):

# Проверка сигнала ESC без мотора

## Условия

- мотор отключён от ESC;
- красный провод BEC из трёхконтактного разъёма изолирован;
- земля ESC соединена с общей землёй управления;
- измерение проводится сначала до кольца, затем через CH5;
- `ENABLE_ESC_ACTIVE_TEST=0`.

## Измерение

| Состояние | Частота | Высокий уровень | Результат |
|---|---:|---:|---|
| После сброса ESP32 | 50 Гц | 1000 мкс | — |
| Команда `PWM 1050` при блокировке | 50 Гц | 1000 мкс | — |
| Команда `SAFE` | 50 Гц | 1000 мкс | — |
| Потеря BLE | 50 Гц | 1000 мкс | — |
| Через CH5 кольца | 50 Гц | 1000 мкс, без пропусков | — |

Активный диапазон 1000–1100 мкс этим протоколом не проверяется. Для него нужен отдельный тест с мотором без ротора, закрытым кожухом, аварийным отключением и подтверждённым направлением вращения.

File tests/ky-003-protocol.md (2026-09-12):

# Проверка датчика Холла KY-003

## Цель

Подтвердить работу модуля от 3,3 В, безопасные уровни на выходе и регистрацию импульса прошивкой ESP32.

## Условия

- ESP32 питается только от USB;
- мотор, ESC, MP1584, LED и токосъёмное кольцо отключены;
- прошивка `firmware/src/main.cpp` загружена;
- Serial Monitor настроен на 115200 бод;
- измерения выполняются мультиметром относительно общего GND.

## Распиновка

Маркировка на конкретном модуле имеет приоритет перед расположением выводов.

| KY-003 | ESP32 | Назначение |
|---|---|---|
| `-` / `GND` | `GND` | Общая земля |
| `+` / `VCC` | `3V3` | Питание 3,3 В |
| `S` / `OUT` | `D27` / GPIO27 | Цифровой сигнал |

Подача 5 В на GPIO27 запрещена. Если модуль не работает от 3,3 В, проверка останавливается до определения маркировки установленного датчика и выбора безопасного согласования уровня.

## Порядок

1. Отключить USB.
2. Сверить `-`, `+` и `S` по шелкографии модуля.
3. Собрать соединения и проверить отсутствие случайных перемычек между соседними выводами.
4. Подключить USB.
5. Измерить `VCC–GND` на модуле.
6. Измерить `OUT–GND` без магнита.
7. Поднести магнит одной стороной, затем другой, не касаясь платы.
8. Записать минимальное и максимальное напряжения OUT.
9. Выполнить `ZERO`, дважды провести магнитом и выполнить `HALL`.
10. Проверить увеличение `count`. Значение `target=NO` при ручном движении нормально.

## Критерии

| Проверка | PASS | FAIL / остановка |
|---|---|---|
| Питание модуля | 3,1–3,5 В | Выход за диапазон |
| OUT, высокий уровень | Не выше 3,5 В | Выше 3,5 В |
| OUT, низкий уровень | Не выше 0,5 В | Уровень не меняется |
| Реакция на магнит | Стабильное переключение хотя бы для одной стороны | Дребезг или отсутствие реакции |
| Счётчик прошивки | Один устойчивый импульс на проход | Пропуски или несколько импульсов на один проход |

## Диагностика

- При отсутствии реакции магнит переворачивается и подносится ближе.
- Вход прошивки проверяется кратковременным соединением GPIO27 с GND; `count` должен увеличиться.
- Если вход ESP32 работает, а модуль не переключается, питание не повышается без отдельной проверки уровня OUT.

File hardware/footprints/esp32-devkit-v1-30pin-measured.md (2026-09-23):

# ESP32 DevKit V1 30-pin — измеренное посадочное место

Статус: шаблон Rev A забракован. Асимметричный шаблон Rev B с шагом 2,52 мм физически проверен 2026-09-23 и принят для первой платы.

## Измеренные размеры

| Параметр | Значение, мм | Статус |
|---|---:|---|
| Ширина платы | 28,50 | Повторно измерено |
| Длина платы без выступа USB | 51,60 | Измерено |
| Максимальная длина с USB | 53,25 | Перемерить после установки нуля |
| Сетка монтажных отверстий по X | 23,30 | Повторно измерено |
| Сетка монтажных отверстий по Y | 46,80 | Повторно измерено |
| Диаметр отверстий модуля | 3,10 | Повторно измерено |
| Ряды контактов, по внешним краям | 26,20 | Повторно измерено |
| Ряды контактов, по внутренним краям | 24,85 | Повторно измерено |
| Расчёт между осями рядов | 25,525 | Среднее внешнего и внутреннего размеров |
| Проектная сетка рядов | 25,40 | Предварительно, стандарт 10 × 2,54 мм |
| Шаг контактов вдоль ряда | 2,54 | Предварительно, проверить |
| Первый–последний контакт одного ряда | 35,30 | Повторно измерено; расчётный стандарт 35,56 |
| Отверстие–крайний контакт | 3,20 | Неясно: центры или края; требует уточнения |
| Высота | 4,70 | Требуется уточнить базовые поверхности |
| Контактов в ряду | 15 | Подтверждено фотографиями |

## Система координат

Начало координат находится в геометрическом центре корпуса платы. Ось X направлена поперёк платы, ось Y — вдоль платы. USB расположен у отрицательного края Y.

Габарит корпуса без USB:

- `X = -14,25…+14,25 мм`;
- `Y = -25,80…+25,80 мм`.

Центры четырёх монтажных отверстий:

- `(-11,65; -23,40)`;
- `(+11,65; -23,40)`;
- `(-11,65; +23,40)`;
- `(+11,65; +23,40)`.

Диаметр отверстий самого модуля — 3,10 мм. Для несущей платы окончательный диаметр или овальная форма выбираются после примерки шаблона.

## Предварительная сетка разъёмов

Для макета допускается сетка двух рядов `2 × 15`, шаг вдоль ряда `2,54 мм`, расстояние между осями рядов `25,40 мм`. Расчётный стандартный пролёт 14 интервалов равен `35,56 мм`; измерено `35,30 мм`. При симметричном размещении координаты рядов будут `X = ±12,70 мм`, а контактов по Y — от `−17,78` до `+17,78 мм` с шагом `2,54 мм`.

Измеренное межосевое расстояние рядов 25,525 мм отличается от стандартной сетки 25,40 мм на 0,125 мм. Для проверочного шаблона применяется номинал 25,40 мм. Производственным размер станет только после физической примерки. Сообщённые `3,20 мм` не используются для координат: при `46,80 мм` между крайними отверстиями и `35,30 мм` между крайними контактами симметричный центр-центр зазор составит `(46,80 − 35,30) / 2 = 5,75 мм`.

## Механическая фиксация

На вращающемся узле одних гнездовых разъёмов недостаточно. ESP32 должна дополнительно фиксироваться четырьмя стойками или отдельным механическим прижимом. USB-разъём требуется оставить доступным только для неподвижной отладки; подключённый USB-кабель при вращении запрещён.

## Проверка перед Gerber

1. Напечатать `esp32-devkit-v1-30pin-template.svg` в масштабе 100% без подгонки страницы.
2. Проверить линейкой контрольный отрезок 50 мм.
3. Приложить ESP32 и проверить все четыре отверстия и оба ряда контактов.
4. Отметить направление и величину любого несовпадения.
5. Только после физической примерки зафиксировать footprint для PCB.

## Результат примерки Rev A

- масштаб печати и общий размер корпуса подтверждены;
- плата относительно рядов контактов асимметрична;
- отверстия рядов `2 × 15` не совпали с ножками;
- координаты контактов Rev A запрещено использовать для PCB и Gerber;
- следующая версия строится по отдельным отступам от четырёх кромок, без предположения о симметрии.
- при совмещении одного крайнего контакта наблюдалось равномерно растущее расхождение до примерно 0,5 мм на другом конце ряда; это отдельно проверяется калибром шага, поскольку фотография платы над непроколотой бумагой содержит параллакс.

Для Rev B измеряются:

- `A` — от кромки платы со стороны антенны до центра крайнего контакта;
- `B` — от кромки платы со стороны USB до центра крайнего контакта;
- `C` — от левой боковой кромки до центра левого ряда;
- `D` — от правой боковой кромки до центра правого ряда.

Контрольные суммы: `A + B + 35,30 ≈ 51,60 мм`, `C + D + 25,525 ≈ 28,50 мм`.

Перед Rev B требуется проверить файл `esp32-header-pitch-gauge.svg`: он содержит три ряда по 15 отверстий с шагом 2,50, 2,52 и 2,54 мм. Бумажные отверстия прокалываются, после чего в них без усилия вставляется один ряд ESP32. В производственном footprint нельзя уменьшать стандартный шаг 2,54 мм только по фотографии или визуальному наложению.

Результат калибра: лучше всего совпал второй ряд, шаг `2,52 мм`, полный пролёт `35,28 мм`. Полный шаблон Rev B проверен с реальной ESP32 и принят. Для Rev A PCB применяются координаты Rev B; замена платы ESP32 на другой экземпляр требует новой примерки.

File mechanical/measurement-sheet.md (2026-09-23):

# Карта измерений деталей

Заполняется после получения компонентов. Размеры указываются в миллиметрах, масса — в граммах.

| Деталь | Длина | Ширина/диаметр | Высота/толщина | Масса | Маркировка | Фото |
|---|---:|---:|---:|---:|---|---|
| Мотор A2212 1000KV | — | — | — | — | — | — |
| Неподвижная крестовина A2212 | 40,50 между крайними точками | — | — | — | — | Фото со штангенциркулем получено |
| Ступица | — | — | — | — | — | — |
| Кольцо | — | — | — | — | — | — |
| ESP32 DevKit V1, 30 pin | 51,60; выступ USB уточнить | 28,50 | 4,70 без уточнения базы измерения | — | ESP32-WROOM-32, CP2102 | Фото сверху и снизу получены |
| MP1584 | — | — | — | — | — | — |
| Лопасть A без электроники | — | — | — | — | — | — |
| Лопасть B без электроники | — | — | — | — | — | — |
| APA102 A с проводами | — | — | — | — | — | — |
| APA102 B с проводами | — | — | — | — | — | — |
| Буфер и переходная плата | — | — | — | — | — | — |
| Полностью собранная сторона A | — | — | — | — | — | — |
| Полностью собранная сторона B | — | — | — | — | — | — |

Дополнительно фиксируются диаметр вала, резьба, межосевые расстояния крепления мотора, отверстие кольца, длина каждой жилы и расстояние центра массы каждой стороны от оси.

## ESP32 DevKit V1 — измерения посадочного места

- корпус платы: `28,50 × 51,60 мм`;
- максимальная длина с USB `53,25 мм` пока требует повторной проверки;
- сетка четырёх монтажных отверстий: `23,30 × 46,80 мм`;
- диаметр монтажного отверстия: `3,10 мм`;
- расстояние между рядами контактов по внутренним краям: `24,85 мм`;
- расстояние между рядами контактов по внешним краям: `26,20 мм`;
- расчётное расстояние между осями рядов: `(24,85 + 26,20) / 2 = 25,525 мм`;
- расстояние между центрами первого и последнего контакта одного ряда: `35,30 мм`;
- бумажный калибр рядов: шаг `2,52 мм` (`35,28 мм` между первым и пятнадцатым контактом); полный шаблон Rev B физически проверен и принят 2026-09-23;
- расстояние, указанное между ближайшим отверстием и крайним контактом: `3,20 мм`; база измерения требует уточнения, так как значение не согласуется с прежней сеткой отверстий;
- измеренная высота: `4,70 мм`; требуется уточнить, включены ли выступающие вниз контакты;
- ожидаемая стандартная сетка рядов: `25,40 мм`, требует проверки шаблоном 1:1 перед изготовлением.

Относительно центра корпуса границы платы находятся в `X = ±14,25 мм`, `Y = ±25,80 мм`. Центры монтажных отверстий находятся в `X = ±11,65 мм`, `Y = ±23,40 мм`. Минимальная перемычка материала корпуса от края отверстия до кромки составляет около `1,05 мм` по ширине и `0,85 мм` по длине.

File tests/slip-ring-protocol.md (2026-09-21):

# Проверка шестиканального кольца

## Цель

Определить соответствие жил, сопротивление и устойчивость контакта при вращении до включения кольца в питание.

## Прозвонка

1. Пронумеровать жилы обеих сторон независимо от цвета.
2. Для каждой жилы найти единственный соответствующий контакт другой стороны.
3. Проверить отсутствие связи с остальными каналами и корпусом.
4. Повторить при медленном вращении на полный оборот.
5. Заполнить `hardware/slip-ring-pinout.md`.

## Сопротивление

Сначала записать сопротивление замкнутых щупов. Из результата каждого канала вычесть это значение. Повторить минимум в восьми угловых положениях.

| Канал | Минимум | Максимум | Скачки/обрывы | Решение |
|---|---:|---:|---|---|
| 1 | — | — | — | — |
| 2 | — | — | — | — |
| 3 | — | — | — | — |
| 4 | — | — | — | — |
| 5 | — | — | — | — |
| 6 | — | — | — | — |

## Нагрузка

Нагрузочный ток назначается только после определения модели кольца. Начать с малого тока от источника с ограничением, измеряя напряжение до и после кольца. Повышать ток ступенями только при отсутствии обрывов и заметного нагрева.

Параллельное соединение CH1+CH2 и CH3+CH4 выполняется после подтверждения, что это одинаковые независимые каналы. Сопротивление и допустимый ток соединения проверяются повторно.

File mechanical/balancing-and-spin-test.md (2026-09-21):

# Балансировка и испытание вращением

## До подачи питания

- обе стороны собраны в окончательной конфигурации;
- масса деталей и расстояния от оси занесены в карту измерений;
- провода закреплены и не могут выйти в плоскость вращения;
- винты имеют механическую фиксацию;
- ротор свободно проходит внутри кожуха с запасом;
- аварийное отключение находится вне плоскости ротора.

## Статическая балансировка

1. Установить ротор на ось с минимальным трением без подключения мотора.
2. Отметить положение после полной остановки.
3. Повторить запуск из восьми разных углов.
4. Если одна сторона систематически оказывается снизу, корректировать массу около того же радиуса на противоположной стороне.
5. Не компенсировать заметный дисбаланс большим грузом у края; сначала устранить различия деталей и проводки.

Статическая балансировка не подтверждает динамическую прочность и отсутствие резонанса.

## Первый spin-test

Испытание проводится только в закрытом ударопрочном кожухе. Запуск с открытым ротором запрещён.

| Ступень | Целевой режим | Выдержка | Контроль |
|---|---|---:|---|
| 0 | Ручное вращение | 1 мин | Касания, проводка, сигнал Hall |
| 1 | Минимально устойчивые обороты | 10 с | Вибрация, звук, смещение |
| 2 | 25% планируемого RPM | 30 с | То же, затем осмотр без питания |
| 3 | 50% | 30 с | То же и температура |
| 4 | 75% | 30 с | Только после анализа предыдущих ступеней |
| 5 | Рабочий RPM | Не назначено | Только после отдельного допуска |

Немедленная остановка требуется при росте вибрации, изменении звука, пропусках Hall, сбросе ESP32, смещении крепежа, касании кожуха, нагреве кольца или провале 5 В ниже 4,70 В. Центробежная нагрузка растёт пропорционально квадрату RPM, поэтому переход между ступенями не считается линейным увеличением риска.

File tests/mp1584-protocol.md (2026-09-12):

# Проверка понижающего преобразователя MP1584

## Цель

Настроить выход 5,00 В и определить устойчивость модуля под нагрузкой до подключения ESP32, светодиодов и токосъёмного кольца.

## Требуется

- регулируемый или защищённый источник постоянного напряжения, соответствующий будущему входу;
- предохранитель или ограничение входного тока;
- мультиметр;
- электронная нагрузка либо мощные нагрузочные резисторы с рассчитанным сопротивлением и мощностью;
- термометр для контроля платы;
- электролитический конденсатор 1000 мкФ с допустимым напряжением не ниже 10 В.

Обычные резисторы 0,25 Вт в качестве силовой нагрузки не применяются.

## Проверка без нагрузки

1. Отключить ESP32, LED, кольцо, ESC и мотор.
2. Установить регулятор MP1584 в среднее положение только при снятом питании, если исходное положение неизвестно.
3. Проверить полярность `IN+`, `IN-`, `OUT+`, `OUT-`.
4. Подать входное питание через ограничение тока.
5. Измерять напряжение непосредственно на `OUT+–OUT-`.
6. Медленно настроить 5,00 В.
7. Отключить и повторно включить питание, затем подтвердить отсутствие выброса выше 5,25 В.

## Нагрузочный тест

Каждая ступень выдерживается не менее 15 минут. Переход к следующей ступени разрешён только после стабильного результата предыдущей.

| Ступень | Ток нагрузки | Назначение |
|---:|---:|---|
| 1 | 0,25 А | Начальный контроль |
| 2 | 0,50 А | Приближённая логическая нагрузка |
| 3 | 1,00 А | Частичная LED-нагрузка |
| 4 | 1,50 А | Планируемый стендовый предел системы |

На каждой ступени фиксируются входное напряжение, выходное напряжение в начале и конце, ток, температура модуля и состояние проводов.

## Критерии

| Проверка | PASS | FAIL / остановка |
|---|---|---|
| Выход без нагрузки | 4,95–5,05 В | Настройка нестабильна |
| Выход под нагрузкой | 4,75–5,25 В без нарастающего падения | Ниже 4,75 В или выше 5,25 В |
| Температура | Стабилизировалась ниже 70 °C | Достигла 70 °C или продолжает расти |
| Проводка и разъёмы | Без заметного нагрева и запаха | Нагрев, потемнение, запах |
| Повторное включение | Без выброса выше 5,25 В | Зафиксирован выброс |

## Конденсатор

Конденсатор 1000 мкФ устанавливается параллельно выходу около нагрузки: `+` к `OUT+`, `-` к `OUT-`. Полярность проверяется до подачи питания.

## Ограничение результата

Успешная проверка MP1584 без кольца не подтверждает работу всей цепи. После проверки кольца нагрузочный тест повторяется с фактической проводкой и разъёмами.

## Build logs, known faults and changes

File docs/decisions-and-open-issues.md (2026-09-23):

# Решения и открытые вопросы

Дата актуализации: 2026-09-23.

## Принятые решения

| Решение | Причина | Условие пересмотра |
|---|---|---|
| ESP32 размещается на роторе | Короткие DATA/CLOCK к двум APA102; через кольцо передаются питание и низкочастотные сигналы | Пересмотреть, если масса и балансировка около оси окажутся неприемлемыми |
| Две лопасти управляются раздельно | Требуется учитывать механический сдвиг 180° | Не пересматривается для двухлопастной версии |
| SN74AHCT125 питается от 5 В | У APA102 при VDD=5 В паспортный `VIH(min)=0,7×VDD=3,5 В`, поэтому прямой сигнал ESP32 3,3 В не гарантирован. У AHCT125 `VIH(min)=2,0 В`, поэтому он надёжно принимает ESP32 и выдаёт 5-вольтовую логику | Заменять только на проверенный быстрый буфер с входным порогом не выше гарантированного `VOH` ESP32; 74HC125 не применять |
| Первая сборка содержит 20 LED на лопасть | Соответствует исходному этапу и снижает нагрузку | 21 LED допускается после измерения и пересчёта питания |
| MP1584 — единственный источник 5 В логики | Исключается параллельная работа с BEC ESC | Менять только после отдельного анализа питания |
| В Rev B MP1584 находится на роторе | Через кольцо передаётся VBAT, а падение в кольце не складывается с низковольтной магистралью 5 В | Пересмотреть после измерения помех, нагрева и сопротивления кольца |
| Домашняя Rev B травится в один слой | Упрощает изготовление и контроль дефектов | Перейти на двухслойную фабричную плату после электрической проверки |
| Активный ESC-тест заблокирован | Ротор, кожух и аварийное отключение ещё не проверены | Разблокировать после выполнения матрицы готовности |

## Открытые вопросы

| ID | Вопрос | Как закрыть | Влияет на |
|---|---|---|---|
| O-01 | Порядок и цвета жил кольца | Прозвонка каждой жилы | Монтаж и схема жгута |
| O-02 | Допустимый ток и сопротивление канала кольца | Паспорт и нагрузочный тест | Яркость и параллельные жилы |
| O-04 | Точные модели ESC и его BEC | Маркировка и инструкция | PWM, питание и BOM |
| O-06 | Геометрия мотора, ступицы и кольца | Штангенциркуль и фотографии | Финальная CAD-модель |
| O-07 | Масса каждого элемента ротора | Весы с разрешением не хуже 0,1 г | Балансировка и RPM |
| O-08 | Тип динамика или зуммера | Выбрать модель, напряжение и ток | Драйвер канала 6 кольца |
| O-09 | Минимальный устойчивый RPM мотора | Стенд без лопастей и тахометр | Пригодность A2212 1000KV |
| O-10 | Номиналы F1 и F2 | Измерение токов и проверка проводки | Силовая схема |

Закрытие вопроса сопровождается измерением, фотографией маркировки или паспортом. Предположение не переводится в подтверждённый факт.

Закрыто 2026-09-21: O-03 — 20 LED занимают 140 мм. Для первой сборки оставлено 20 LED на лопасть.

Закрыто 2026-09-21: O-05 — при виде на компонентную сторону KY-003 выводы слева направо обозначены `-`, `+`, `S`. Проверена работа от 3,3 В; для устойчивого высокого уровня установлен внешний резистор 10 кОм между `+` и `S`.

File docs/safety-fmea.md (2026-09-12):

# Актуальная предварительная FMEA

Оценки предварительные: S — тяжесть, L — вероятность, D — сложность обнаружения, по шкале 1–10; RPN = S × L × D.

| Отказ | S | L | D | RPN | Обязательная мера |
|---|---:|---:|---:|---:|---|
| Разрушение или отрыв лопасти | 10 | 4 | 7 | 280 | Несущая балка, металлическая ступица, расчёт, испытания и закрытый кожух |
| Дисбаланс двух лопастей | 9 | 5 | 4 | 180 | Взвешивание, статическая и динамическая балансировка полной сборки |
| Ослабление крепежа/проводов | 9 | 4 | 6 | 216 | Механическая фиксация, контровка, разгрузка пайки, осмотр перед каждым пуском |
| Превышение оборотов A2212 | 10 | 4 | 5 | 200 | Независимое измерение RPM, ограничение PWM, физический выключатель, кожух |
| Перегрузка MP1584 при 42 LED | 8 | 5 | 3 | 120 | Ограничение LED-тока, нагрузочный тест, переход на 5 В ≥4 А при необходимости |
| Перегрев кольца из-за неравного тока каналов | 8 | 5 | 5 | 200 | Измерить сопротивление каналов, напряжение и температуру под нагрузкой |
| Прерывание PWM через кольцо | 10 | 3 | 6 | 180 | Pull-down у ESC, контроль осциллографом, watchdog и безопасные 1000 мкс |
| Потеря Hall | 8 | 4 | 3 | 96 | LED off, ESC safe, диагностика и жёсткое крепление магнита |
| Hall выдаёт 5 В на GPIO27 | 7 | 3 | 4 | 84 | Питать KY-003 от 3,3 В и измерить OUT до подключения |
| Ошибка DATA/CLOCK одной лопасти | 5 | 4 | 2 | 40 | Четыре канала AHCT, четыре резистора, раздельный тест ветвей |
| Li-Po короткое замыкание/пожар | 10 | 3 | 5 | 150 | XT60, предохранитель, проводка нужного сечения, безопасная зарядка и хранение |
| USB оставлен при вращении | 10 | 2 | 3 | 60 | Физически снять кабель до подачи питания ESC |

Остаточный риск не допускает открытого вращения. Программные ограничения не заменяют кожух, балансировку и механическую прочность.

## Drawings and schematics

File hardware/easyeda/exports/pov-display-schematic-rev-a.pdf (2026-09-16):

# POV DISPLAY STATIONARY POWER, MOTOR AND SLIP RING

J1

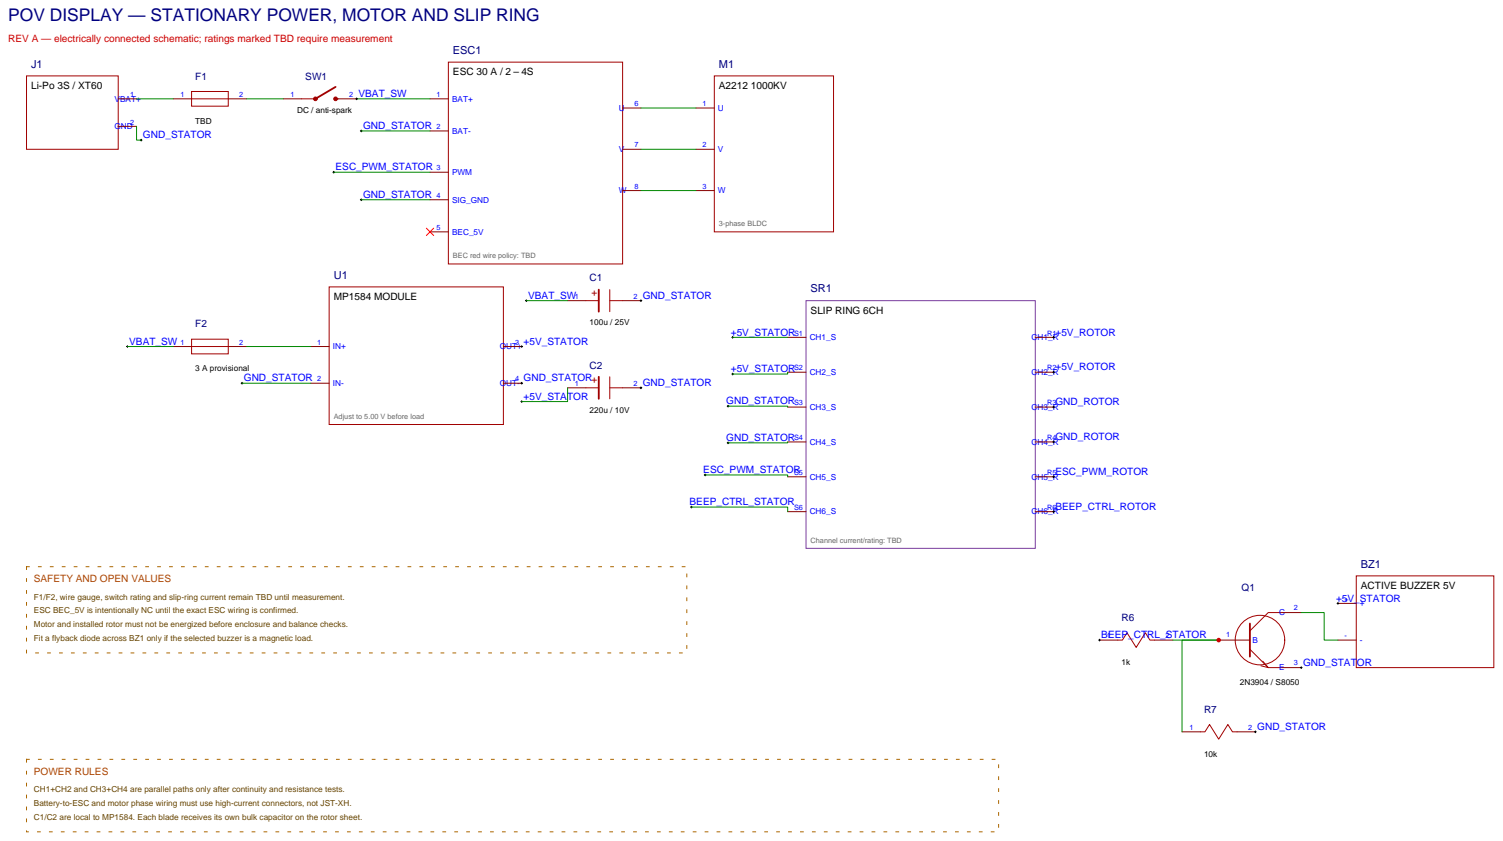
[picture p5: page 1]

REV A electrically connected schematic; ratings marked TBD require measurement

BEC red wire policy: TBD

Adjust to 5.00 V before load

Channel current/rating: TBD

SAFETY AND OPEN VALUES
F1/F2, wire gauge, switch rating and slip-ring current remain TBD until measurement.
ESC BEC_5V is intentionally NC until the exact ESC wiring is confirmed.
Motor and installed rotor must not be energized before enclosure and balance checks.
Fit a flyback diode across BZ1 only if the selected buzzer is a magnetic load.

POWER RULES
CH1+CH2 and CH3+CH4 are parallel paths only after continuity and resistance tests.
Battery-to-ESC and motor phase wiring must use high-current connectors, not JST-XH.
C1/C2 are local to MP1584. Each blade receives its own bulk capacitor on the rotor sheet.

# POV DISPLAY ROTOR CONTROLLER, HALL SENSOR AND TWO APA102 BLADES

U3

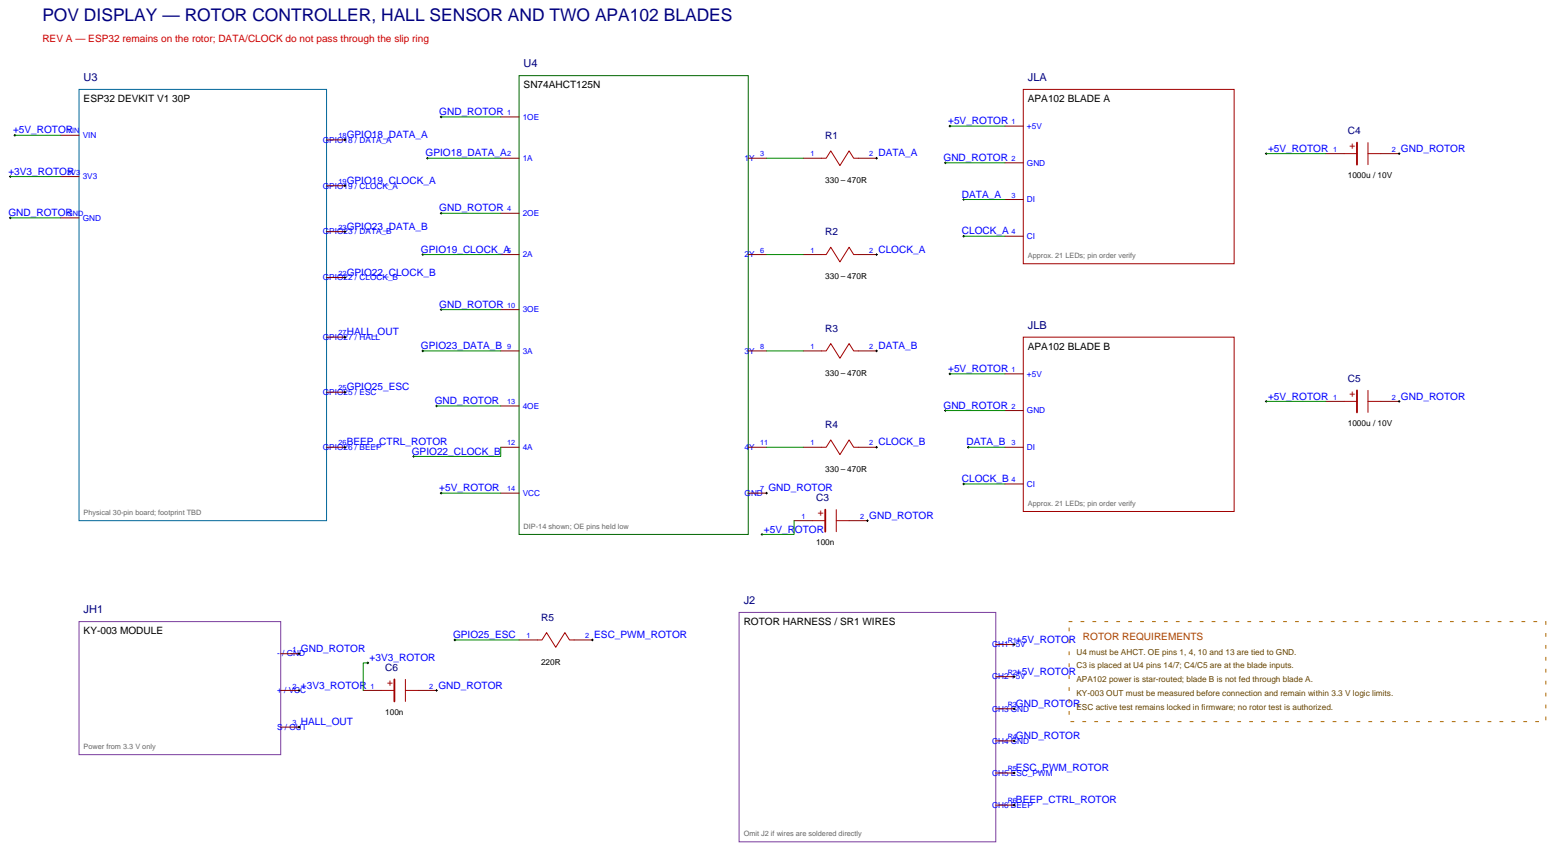
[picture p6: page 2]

REV A ESP32 remains on the rotor; DATA/CLOCK do not pass through the slip ring

Approx. 21 LEDs; pin order verify

Physical 30-pin board; footprint TBD

DIP-14 shown; OE pins held low

ROTOR REQUIREMENTS
U4 must be AHCT. OE pins 1, 4, 10 and 13 are tied to GND.
C3 is placed at U4 pins 14/7; C4/C5 are at the blade inputs.
APA102 power is star-routed; blade B is not fed through blade A.
KY-003 OUT must be measured before connection and remain within 3.3 V logic limits.
ESC active test remains locked in firmware; no rotor test is authorized.

Omit J2 if wires are soldered directly

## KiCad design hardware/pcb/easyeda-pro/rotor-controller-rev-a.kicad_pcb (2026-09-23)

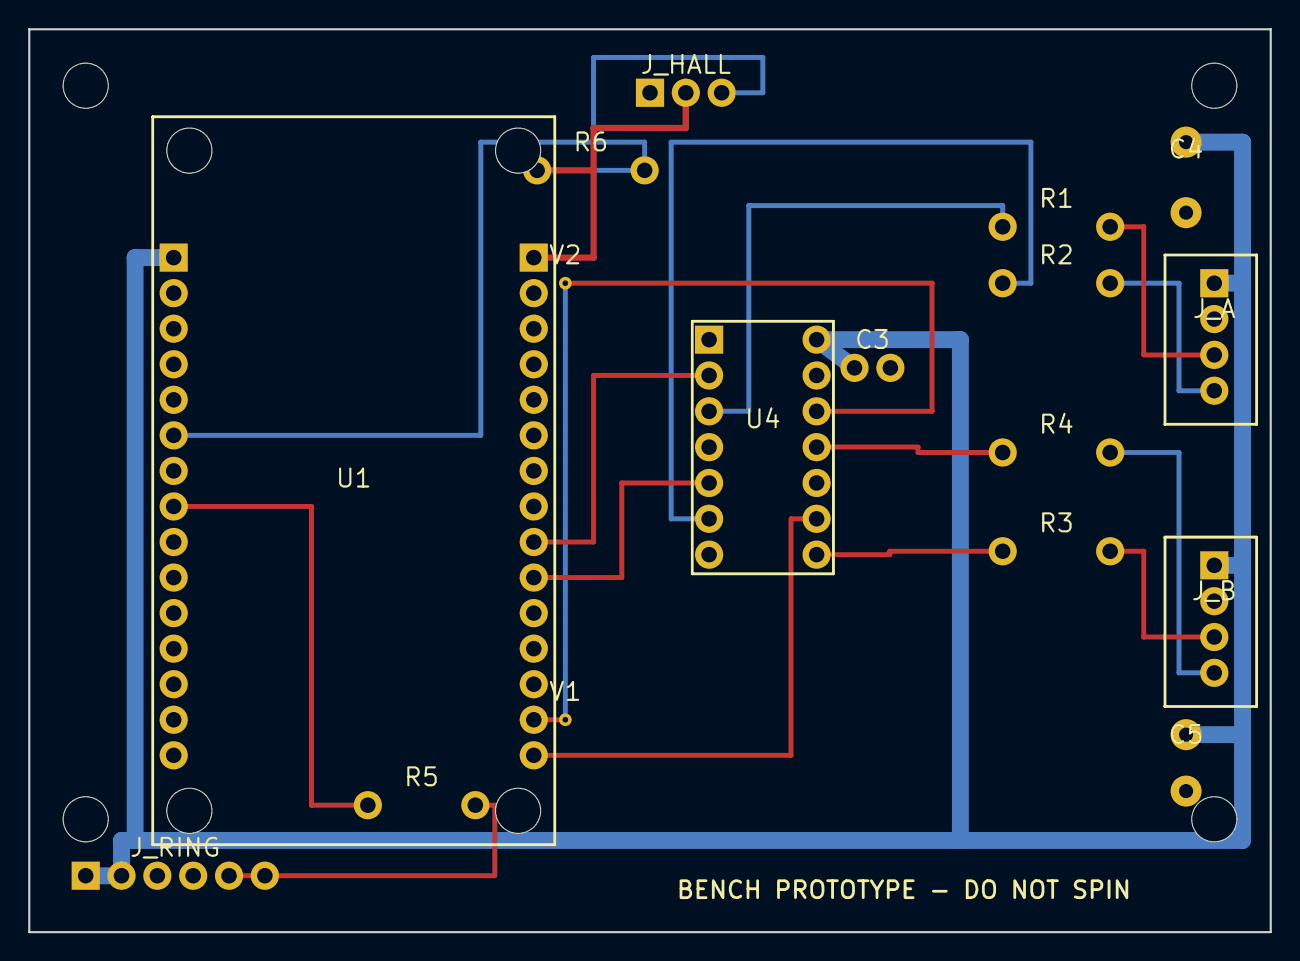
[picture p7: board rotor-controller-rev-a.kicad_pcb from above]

Board: 2 copper layers, 88.0 x 64.0 mm, 25 parts (0 on the bottom side), 18 nets.

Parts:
C3: C3
C4: C4
C5: C5
J_A: J_A
J_B: J_B
J_HALL: J_HALL
J_RING: J_RING
PCB-M3, PCB-M3#2, PCB-M3#3, PCB-M3#4: NPTH 3.2mm; PCB-M3
R1: R1
R2: R2
R3: R3
R4: R4
R5: R5
R6: R6
U1: U1
U1-MOUNT, U1-MOUNT#2, U1-MOUNT#3, U1-MOUNT#4: NPTH 3.2mm; U1-MOUNT
U4: U4
V1: V1
V2: V2

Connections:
3V3: J_HALL.2, R6.1, U1.R1-3V3
5V: C3.1, C4.1, C5.1, J_A.1, J_B.1, J_RING.1, J_RING.2, U1.L1-VIN, U4.14
CLOCK_A: J_A.4, R2.2
CLOCK_A_3V3: U1.R10-D19, U4.5
CLOCK_A_BUF: R2.1, U4.6
CLOCK_B: J_B.4, R4.2
CLOCK_B_3V3: U1.R14-D22, U4.12, V1.1, V2.1
CLOCK_B_BUF: R4.1, U4.11
DATA_A: J_A.3, R1.2
DATA_A_3V3: U1.R9-D18, U4.2
DATA_A_BUF: R1.1, U4.3
DATA_B: J_B.3, R3.2
DATA_B_3V3: U1.R15-D23, U4.9
DATA_B_BUF: R3.1, U4.8
ESC_PWM: J_RING.5, R5.2
ESC_PWM_3V3: R5.1, U1.L8-D25
GND: C3.2, C4.2, C5.2, J_A.2, J_B.2, J_HALL.1, J_RING.3, J_RING.4, U1.L2-GND, U1.R2-GND, U4.1, U4.4, U4.7, U4.10, U4.13
HALL: J_HALL.3, R6.2, U1.L6-D27

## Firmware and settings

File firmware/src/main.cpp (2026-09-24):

#include <Arduino.h>
#include <BLE2902.h>
#include <BLEDevice.h>
#include <BLEServer.h>
#include <BLEUtils.h>
#include <Preferences.h>

#include "esc_controller.h"
#include "pov_renderer.h"
#include "project_config.h"

namespace {

BLEUUID serviceUuid("7dc00001-7b7a-4c6a-9f4b-0b62025a0001");
BLEUUID commandUuid("7dc00002-7b7a-4c6a-9f4b-0b62025a0001");
BLEUUID statusUuid("7dc00003-7b7a-4c6a-9f4b-0b62025a0001");
constexpr uint32_t IMAGE_MAGIC = 0x504F5631;
constexpr char PREF_NAMESPACE[] = "pov-display";

portMUX_TYPE hallMux = portMUX_INITIALIZER_UNLOCKED;
volatile uint32_t hallLastUs = 0;
volatile uint32_t hallPeriodUs = 0;
volatile uint32_t hallPulseCount = 0;
volatile uint32_t hallRejectedCount = 0;
volatile bool hallEventPending = false;

BLECharacteristic *statusCharacteristic = nullptr;
bool bleConnected = false;
uint32_t lastStatusMs = 0;
String serialLine;
PovRenderer povRenderer;
EscController escController;

uint32_t elapsed32(uint32_t now, uint32_t then) { return now - then; }

void IRAM_ATTR onHallPulse() {
  const uint32_t now = micros();
  portENTER_CRITICAL_ISR(&hallMux);
  const uint32_t previous = hallLastUs;
  const uint32_t delta = elapsed32(now, previous);
  if (previous == 0 || delta >= config::HALL_DEBOUNCE_US) {
    hallLastUs = now;
    if (previous != 0) {
      hallPeriodUs = hallPeriodUs == 0
          ? delta
          : static_cast<uint32_t>((static_cast<uint64_t>(hallPeriodUs) * 3ULL +
                                   delta) / 4ULL);
    }
    ++hallPulseCount;
    hallEventPending = true;
  } else {
    ++hallRejectedCount;
  }
  portEXIT_CRITICAL_ISR(&hallMux);
}

struct HallSnapshot {
  uint32_t lastUs;
  uint32_t periodUs;
  uint32_t count;
  uint32_t rejected;
  bool eventPending;
};

HallSnapshot readHall(bool clearEvent = false) {
  HallSnapshot snapshot{};
  portENTER_CRITICAL(&hallMux);
  snapshot.lastUs = hallLastUs;
  snapshot.periodUs = hallPeriodUs;
  snapshot.count = hallPulseCount;
  snapshot.rejected = hallRejectedCount;
  snapshot.eventPending = hallEventPending;
  if (clearEvent) hallEventPending = false;
  portEXIT_CRITICAL(&hallMux);
  return snapshot;
}

float rpmFromPeriod(uint32_t periodUs) {
  return periodUs == 0 ? 0.0f : 60000000.0f / static_cast<float>(periodUs);
}

bool hallIsRecent(const HallSnapshot &hall, uint32_t nowUs) {
  return hall.lastUs != 0 &&
         elapsed32(nowUs, hall.lastUs) <= config::HALL_STATUS_TIMEOUT_US;
}

String hallStatusText() {
  const HallSnapshot hall = readHall();
  const bool recent = hallIsRecent(hall, micros());
  const float rpm = recent ? rpmFromPeriod(hall.periodUs) : 0.0f;
  String result = "HALL count=";
  result += hall.count;
  result += " rejected=";
  result += hall.rejected;
  result += " period_us=";
  result += recent ? String(hall.periodUs) : String(0);
  result += " rpm=";
  result += String(rpm, 1);
  result += " target=";
  result += (rpm >= config::TARGET_RPM_MIN && rpm <= config::TARGET_RPM_MAX)
                ? "YES" : "NO";
  return result;
}

void publishStatus(const String &message) {
  Serial.println(message);
  if (statusCharacteristic != nullptr && bleConnected) {
    statusCharacteristic->setValue(message.c_str());
    statusCharacteristic->notify();
  }
}

void resetHallCounters() {
  portENTER_CRITICAL(&hallMux);
  hallLastUs = 0;
  hallPeriodUs = 0;
  hallPulseCount = 0;
  hallRejectedCount = 0;
  hallEventPending = false;
  portEXIT_CRITICAL(&hallMux);
  publishStatus("OK hall counters cleared");
}

uint32_t imageChecksum(const uint8_t *data, size_t length) {
  uint32_t hash = 2166136261UL;
  for (size_t i = 0; i < length; ++i) hash = (hash ^ data[i]) * 16777619UL;
  return hash;
}

bool saveImage() {
  Preferences preferences;
  if (!preferences.begin(PREF_NAMESPACE, false)) return false;
  const size_t length = povRenderer.imageByteCount();
  bool ok = preferences.putUInt("magic", IMAGE_MAGIC) == sizeof(uint32_t);
  ok = preferences.putUInt("length", length) == sizeof(uint32_t) && ok;
  ok = preferences.putUInt("checksum", imageChecksum(povRenderer.imageBytes(), length)) == sizeof(uint32_t) && ok;
  ok = preferences.putUChar("bright", povRenderer.brightness()) == sizeof(uint8_t) && ok;
  ok = preferences.putShort("phase", povRenderer.phaseOffset()) == sizeof(int16_t) && ok;
  ok = preferences.putBytes("image", povRenderer.imageBytes(), length) == length && ok;
  preferences.end();
  return ok;
}

bool loadImage() {
  Preferences preferences;
  if (!preferences.begin(PREF_NAMESPACE, true)) return false;
  const size_t expected = povRenderer.imageByteCount();
  const bool headerOk = preferences.getUInt("magic", 0) == IMAGE_MAGIC &&
                        preferences.getUInt("length", 0) == expected &&
                        preferences.getBytesLength("image") == expected;
  bool ok = false;
  if (headerOk && preferences.getBytes("image", povRenderer.imageBytes(), expected) == expected) {
    ok = preferences.getUInt("checksum", 0) ==
         imageChecksum(povRenderer.imageBytes(), expected);
    if (ok) {
      povRenderer.setBrightness(preferences.getUChar("bright", config::APA102_GLOBAL_BRIGHTNESS));
      povRenderer.setPhaseOffset(preferences.getShort("phase", 0));
    }
  }
  preferences.end();
  return ok;
}

bool parseImageCommand(const String &command) {
  int column, radius, red, green, blue;
  if (sscanf(command.c_str(), "IMAGE PIXEL %d %d %d %d %d", &column, &radius,
             &red, &green, &blue) == 5) {
    if (red < 0 || red > 255 || green < 0 || green > 255 || blue < 0 ||
        blue > 255 || !povRenderer.setPixel(column, radius,
          {static_cast<uint8_t>(red), static_cast<uint8_t>(green), static_cast<uint8_t>(blue)})) {
      publishStatus("ERR IMAGE PIXEL range");
    } else publishStatus("OK IMAGE PIXEL");
    return true;
  }
  if (sscanf(command.c_str(), "IMAGE CLEAR %d %d %d", &red, &green, &blue) == 3) {
    if (red < 0 || red > 255 || green < 0 || green > 255 || blue < 0 || blue > 255) {
      publishStatus("ERR IMAGE CLEAR range");
    } else {
      povRenderer.fillImage({static_cast<uint8_t>(red), static_cast<uint8_t>(green), static_cast<uint8_t>(blue)});
      publishStatus("OK IMAGE CLEAR");
    }
    return true;
  }
  if (command == "IMAGE PATTERN") {
    povRenderer.buildDiagnosticImage();
    publishStatus("OK IMAGE PATTERN");
    return true;
  }
  if (command == "IMAGE SAVE") {
    publishStatus(saveImage() ? "OK IMAGE SAVED" : "ERR IMAGE SAVE");
    return true;
  }
  if (command == "IMAGE LOAD") {
    publishStatus(loadImage() ? "OK IMAGE LOADED" : "ERR IMAGE LOAD");
    return true;
  }
  if (command == "IMAGE STATUS") {
    publishStatus("IMAGE columns=" + String(config::ANGULAR_COLUMNS) +
                  " leds=" + String(config::LEDS_PER_BLADE) +
                  " brightness=" + String(povRenderer.brightness()) +
                  " phase=" + String(povRenderer.phaseOffset()));
    return true;
  }
  return false;
}

void handleCommand(String command) {
  command.trim();
  command.toUpperCase();
  if (command.isEmpty() || parseImageCommand(command)) return;
  if (command == "PING") { publishStatus("PONG"); return; }
  if (command == "VERSION") {
    publishStatus("VERSION " + String(config::FIRMWARE_VERSION));
    return;
  }
  if (command == "STATUS") {
    publishStatus(hallStatusText());
    publishStatus(escController.statusText());
    return;
  }
  if (command == "HALL") { publishStatus(hallStatusText()); return; }
  if (command == "ESCSTATUS") { publishStatus(escController.statusText()); return; }
  if (command == "POVSTATUS") {
    String status = "POV build=";
    status += config::POV_OUTPUT_ENABLED ? "ENABLED" : "LOCKED";
    status += " sync=";
    status += povRenderer.hasSynchronization() ? "YES" : "NO";
    status += " column=";
    status += povRenderer.currentColumn() == UINT16_MAX ? String("NONE") : String(povRenderer.currentColumn());
    publishStatus(status);
    return;
  }
  if (command == "ZERO") { resetHallCounters(); return; }
  if (command.startsWith("SIMRPM ")) {
    const long rpm = command.substring(7).toInt();
    if (rpm < 1 || rpm > 10000) publishStatus("ERR SIMRPM range is 1..10000");
    else publishStatus("SIM rpm=" + String(rpm) + " period_us=" + String(60000000UL / static_cast<uint32_t>(rpm)));
    return;
  }
  if (command == "ARM") {
    publishStatus(escController.requestArm(millis())
      ? "CONFIRM with ARM CONFIRM within 3 s" : "ERR ARM locked or faulted");
    return;
  }
  if (command == "ARM CONFIRM") {
    publishStatus(escController.confirmArm(millis()) ? "OK ESC ARMED" : "ERR ARM confirmation");
    return;
  }
  if (command == "KEEPALIVE") {
    escController.keepAlive(millis());
    publishStatus("OK KEEPALIVE");
    return;
  }
  if (command == "RESETFAULT") {
    escController.clearFault();
    publishStatus(escController.statusText());
    return;
  }
  if (command.startsWith("THROTTLE ") || command.startsWith("PWM ")) {
    const int requestedUs = command.substring(command.indexOf(' ') + 1).toInt();
    publishStatus(escController.setThrottle(requestedUs, millis())
      ? "OK THROTTLE=" + String(requestedUs) : "ERR THROTTLE locked, unarmed or range");
    return;
  }
  if (command == "SAFE" || command == "STOP" || command == "OFF" || command == "DISARM") {
    escController.stop();
    povRenderer.blackout();
    publishStatus("SAFE ESC=1000 us POV=BLACK");
    return;
  }
  if (command.startsWith("BRIGHT ")) {
    const int brightness = command.substring(7).toInt();
    if (brightness < 0 || brightness > 31) publishStatus("ERR BRIGHT range 0..31");
    else { povRenderer.setBrightness(brightness); publishStatus("OK BRIGHT=" + String(brightness)); }
    return;
  }
  if (command.startsWith("PHASE ")) {
    povRenderer.setPhaseOffset(command.substring(6).toInt());
    publishStatus("OK PHASE=" + String(povRenderer.phaseOffset()));
    return;
  }
  if (command == "HELP") {
    publishStatus("CMDS STATUS ARM/CONFIRM THROTTLE KEEPALIVE STOP IMAGE BRIGHT PHASE");
    return;
  }
  publishStatus("ERR unknown command; send HELP");
}

class ServerCallbacks final : public BLEServerCallbacks {
  void onConnect(BLEServer *) override {
    bleConnected = true;
    publishStatus("BLE connected; ESC remains disarmed");
  }
  void onDisconnect(BLEServer *server) override {
    bleConnected = false;
    escController.stop();
    povRenderer.blackout();
    server->getAdvertising()->start();
    Serial.println("BLE disconnected; SAFE");
  }
};

class CommandCallbacks final : public BLECharacteristicCallbacks {
  void onWrite(BLECharacteristic *characteristic) override {
    const std::string value = characteristic->getValue();
    if (!value.empty()) handleCommand(String(value.c_str()));
  }
};

void setupBle() {
  BLEDevice::init("POV-Display");
  BLEServer *server = BLEDevice::createServer();
  server->setCallbacks(new ServerCallbacks());
  BLEService *service = server->createService(serviceUuid);
  BLECharacteristic *commandCharacteristic = service->createCharacteristic(
      commandUuid, BLECharacteristic::PROPERTY_WRITE | BLECharacteristic::PROPERTY_WRITE_NR);
  commandCharacteristic->setCallbacks(new CommandCallbacks());
  statusCharacteristic = service->createCharacteristic(
      statusUuid, BLECharacteristic::PROPERTY_READ | BLECharacteristic::PROPERTY_NOTIFY);
  statusCharacteristic->addDescriptor(new BLE2902());
  statusCharacteristic->setValue("BOOT SAFE");
  service->start();
  BLEAdvertising *advertising = BLEDevice::getAdvertising();
  advertising->addServiceUUID(serviceUuid);
  advertising->setScanResponse(true);
  advertising->start();
}

void readSerialCommands() {
  while (Serial.available() > 0) {
    const char c = static_cast<char>(Serial.read());
    if (c == '\r') continue;
    if (c == '\n') {
      handleCommand(serialLine);
      serialLine = "";
    } else if (serialLine.length() < 127) serialLine += c;
  }
}

}  // namespace

void setup() {
  Serial.begin(115200);
  delay(300);
  Serial.println("\nESP32 POV project firmware");
  Serial.println("Version: " + String(config::FIRMWARE_VERSION));
  pinMode(config::HALL_PIN, INPUT_PULLUP);
  attachInterrupt(digitalPinToInterrupt(config::HALL_PIN), onHallPulse, FALLING);
  escController.begin();
  povRenderer.buildDiagnosticImage();
  const bool restored = loadImage();
  if (config::POV_OUTPUT_ENABLED) povRenderer.begin();
  setupBle();
  Serial.println("BLE name: POV-Display");
  Serial.println(restored ? "Stored image loaded" : "Diagnostic image loaded");
  Serial.println(config::POV_OUTPUT_ENABLED ? "POV ENABLED" : "POV BUILD LOCKED");
  Serial.println(config::ESC_ACTIVE_TEST_ENABLED ? "ESC control DISARMED" : "ESC BUILD LOCKED");
  Serial.println("READY SAFE PWM=1000 us");
}

void loop() {
  readSerialCommands();
  const uint32_t nowUs = micros();
  const uint32_t nowMs = millis();
  const HallSnapshot hall = readHall(true);
  const bool recent = hallIsRecent(hall, nowUs);
  const float rpm = recent ? rpmFromPeriod(hall.periodUs) : 0.0f;

  if (hall.eventPending) {
    Serial.println("PULSE " + hallStatusText());
    if (config::POV_OUTPUT_ENABLED && hall.periodUs != 0)
      povRenderer.synchronize(hall.lastUs, hall.periodUs);
  }
  if (config::POV_OUTPUT_ENABLED) povRenderer.tick(nowUs);

  const EscController::State before = escController.state();
  escController.tick(nowMs, nowUs, hall.lastUs, rpm);
  if (before != EscController::State::FAULT &&
      escController.state() == EscController::State::FAULT) {
    povRenderer.blackout();
    publishStatus(escController.statusText());
  }
  if (nowMs - lastStatusMs >= config::STATUS_PERIOD_MS) {
    lastStatusMs = nowMs;
    publishStatus(hallStatusText());
  }
  delay(2);
}

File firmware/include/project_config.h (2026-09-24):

#pragma once

#include <Arduino.h>

#ifndef POV_DISPLAY_ENABLED
#define POV_DISPLAY_ENABLED 0
#endif

#ifndef ENABLE_ESC_ACTIVE_TEST
#define ENABLE_ESC_ACTIVE_TEST 0
#endif

namespace config {

constexpr char FIRMWARE_VERSION[] = "1.0.0-project";

constexpr uint8_t HALL_PIN = 27;
constexpr uint8_t ESC_PIN = 25;

constexpr uint8_t LED_DATA_A_PIN = 18;
constexpr uint8_t LED_CLOCK_A_PIN = 19;
constexpr uint8_t LED_DATA_B_PIN = 23;
constexpr uint8_t LED_CLOCK_B_PIN = 22;

constexpr uint8_t ESC_CHANNEL = 0;
constexpr uint16_t ESC_FREQUENCY_HZ = 50;
constexpr uint8_t ESC_RESOLUTION_BITS = 16;
constexpr uint16_t ESC_SAFE_US = 1000;
constexpr uint16_t ESC_MAX_US = 1600;
constexpr uint16_t ESC_HALL_REQUIRED_US = 1050;
constexpr uint16_t ESC_RAMP_STEP_US = 5;
constexpr uint32_t ESC_RAMP_PERIOD_MS = 20;
constexpr uint32_t ESC_ARM_CONFIRM_TIMEOUT_MS = 3000;
constexpr uint32_t ESC_HEARTBEAT_TIMEOUT_MS = 1000;
constexpr uint32_t ESC_STARTUP_HALL_TIMEOUT_MS = 3000;
constexpr uint32_t ESC_RUNNING_HALL_TIMEOUT_US = 500000;
constexpr uint16_t ESC_HARD_RPM_LIMIT = 2600;

constexpr uint8_t LEDS_PER_BLADE = 20;
constexpr uint16_t ANGULAR_COLUMNS = 120;
constexpr uint8_t APA102_GLOBAL_BRIGHTNESS = 3;  // 3/31 for first tests.
constexpr uint32_t APA102_SPI_HZ = 12000000;

constexpr uint32_t HALL_DEBOUNCE_US = 5000;
constexpr uint32_t HALL_STATUS_TIMEOUT_US = 2000000;
constexpr uint32_t POV_SYNC_TIMEOUT_US = 250000;
constexpr uint16_t TARGET_RPM_MIN = 600;
constexpr uint16_t TARGET_RPM_MAX = 2400;
constexpr uint32_t STATUS_PERIOD_MS = 1000;

constexpr bool POV_OUTPUT_ENABLED = POV_DISPLAY_ENABLED != 0;
constexpr bool ESC_ACTIVE_TEST_ENABLED = ENABLE_ESC_ACTIVE_TEST != 0;

static_assert(ANGULAR_COLUMNS % 2 == 0,
              "Two blades require an even angular column count");
static_assert(LEDS_PER_BLADE >= 1 && LEDS_PER_BLADE <= 21,
              "Verify power and geometry before using more than 21 LEDs");
static_assert(ESC_MAX_US >= ESC_SAFE_US,
              "ESC maximum pulse must not be below the safe pulse");
static_assert(ESC_HARD_RPM_LIMIT > TARGET_RPM_MAX,
              "Hard RPM limit must be above the intended working range");

}  // namespace config

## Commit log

2026-09-12 wiring done
    [wiring-netlist.csv]
2026-09-12 draft model
    [preliminary-assembly.scad]
2026-09-16 schematic pdf
2026-09-21 hall test done
2026-09-23 level shifter and pcb draft
2026-09-23 gerber rev a
    [pad-map.csv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]
2026-09-23 rotor mounting and tests
    [pad-map.csv, rotor-controller-rev-a.kicad_pcb, rotor-controller-rev-b-home-etch.kicad_pcb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]
2026-09-30 Add Rev C PCB files and printable STL set
2026-10-09 Strengthen printable fan enclosure and remove legacy CAD
2026-10-13 Add rear switch opening to fan base
2026-10-13 Document Rev C power-stage bench results
2026-10-13 Record measured coil geometry and cable exits
2026-10-13 Add printable inductive coil carriers
2026-10-13 Fix receiver board carrier wall
2026-10-13 Route motor wiring through pedestal
2026-10-13 Add bed-packed STL export sets
2026-10-14 Add Hall magnet guard mount
2026-10-19 Consolidate Rev C documentation and CAD records
